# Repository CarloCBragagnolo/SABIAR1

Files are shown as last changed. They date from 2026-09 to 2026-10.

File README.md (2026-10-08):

# SABIAR1



Project files for the Sabiá R1 flight computer

These are the kicad files for the ESP32S3 based flight computer I designed over the summer, Sabiá R1. This is intended as a practise project to improve my skills in programming and pcb design. There are, however, known issues with the design that anyone who uses this design should adress:
first, in the BOM file attached, one of the current limiting/voltage divider resistors in the pyro channels is 7.5 $\ohm$, when it should be 7.5k, causing the led to fail upon arming the pyro channel. Further, the battery voltage measurement circuit was mistakenly connected to a pin with no ADC, so it does not work. Testing is still ongoing so I will keep this page updated.
## DEPENDENCIES
The computer is dependand on the [LIS3MDL](https://github.com/CarloCBragagnolo/lis3mdl) and [LSM6DS3](https://github.com/CarloCBragagnolo/LSM6DS3) libraries, published by myself and available on arduino, as well as the adafruit BMP280 library, also available on arduino. ArduinoEigenDense is also used to handle linear algebra.
## UPDATE 08/10/2026

I have replaced the faulty resistors with the correct valued ones, and this validated the continuity testing, both at the GPIO pin and the LED. Further, the pyros were tested and shown to work, melting through a thin copper wire at 150ms firing time, drawing a estimated 3 amps. No tests have been conducted on a live pyro charge.

Regarding flight software, the attitude kalman filter has been updated to use the magnetometer for up-down facing disambiguation, allowing for accurate logging throughout the flight envelope. Also, the magnetometer can now take both soft and hard iron calibration. The relevant paremeters were calculated using MagMaster. Furthermore, dead-reckoning was added for the y and z axes. This is very much experimental and is not recomended to be used in any flight logic (eg. deploy parachutes early if too far down range).

## TEST FOOTAGE

https://github.com/user-attachments/assets/4542bc1e-f65c-4ce2-99e9-89a8cd237ede

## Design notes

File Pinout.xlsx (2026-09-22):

1 | BUZZER PWM
2 | PYRO 1
3 | PYRO 2
4 | NC
5 | NC
6 | CS BAROMETER
7 | CS MAGNETOMETER
8 | AVAILABLE
9 | AVAILABLE
10 | CS IMU
11 | MOSI
12 | CLK
13 | MISO
14 | NC
15 | NC
16 | NC
17 | LED1
18 | LED3
19 | NC
20 | NC
21 | LED2
22 | NC
23 | NC
24 | NC
25 | NC
26 | NC
27 | NC
28 | NC
29 | NC
30 | NC
31 | NC
32 | NC
33 | NC
34 | NC
35 | NC
36 | PY1 VOLTAGE - dead
37 | PY2 VOLTAGE - dead
38 | BATT CONT.
39 | NC
40 | NC
41 | NC
42 | NC
43 | NC
44 | NC
45 | NC
46 | NC
47 | NC
48 | NC

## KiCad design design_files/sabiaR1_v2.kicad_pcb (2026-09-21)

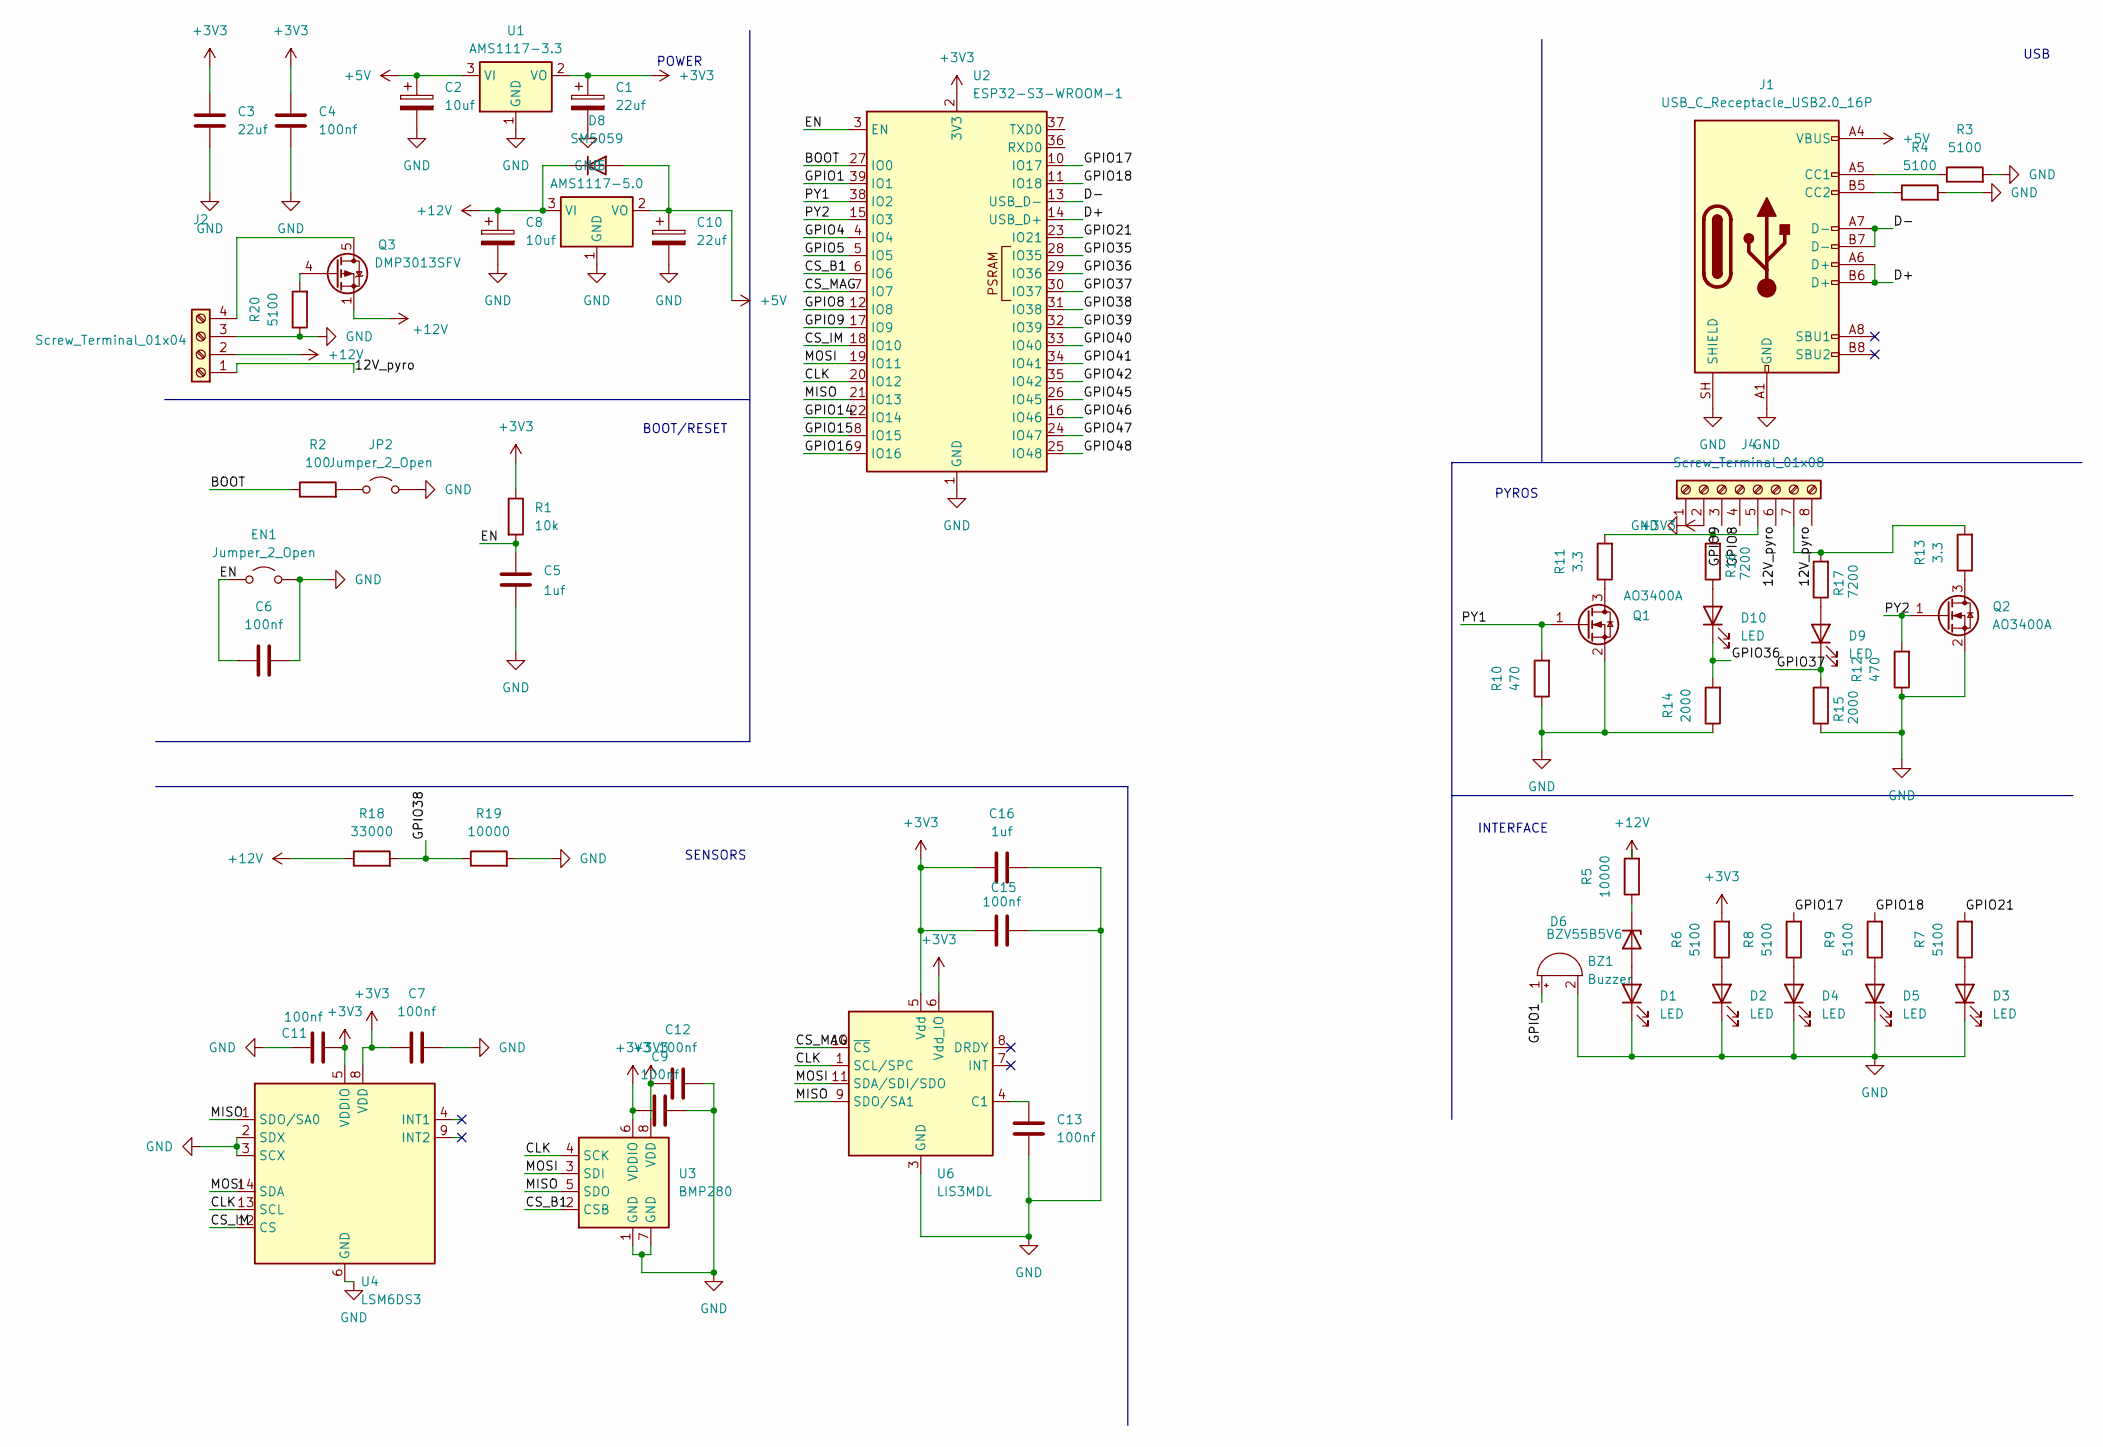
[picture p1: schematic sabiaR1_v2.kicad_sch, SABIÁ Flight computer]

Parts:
BZ1: Buzzer; Buzzer_CUI_CPT-9019S-SMT
C1, C10: 22uf; CP_EIA-3216-18_Kemet-A
C2, C8: 10uf; CP_EIA-3216-12_Kemet-S
C3: 22uf; C_0402_1005Metric
C4, C6, C7, C9, C11, C12, C13, C15: 100nf; C_0402_1005Metric
C5, C16: 1uf; C_0402_1005Metric
D1, D2, D3, D4, D5, D9, D10: LED; LED_0603_1608Metric
D6: BZV55B5V6; D_SOD-923
D8: SM5059; D_SOD-123F
EN1: Jumper_2_Open; SolderJumper-2_P1.3mm_Open_Pad1.0x1.5mm
J1: USB_C_Receptacle_USB2.0_16P; USB_C_Receptacle_GCT_USB4105-xx-A_16P_TopMnt_Horizontal
J2: Screw_Terminal_01x04; TerminalBlock_Phoenix_PT-1,5-4-3.5-H_1x04_P3.50mm_Horizontal
J4: Screw_Terminal_01x08; TerminalBlock_Phoenix_PT-1,5-8-3.5-H_1x08_P3.50mm_Horizontal
JP2: Jumper_2_Open; SolderJumper-2_P1.3mm_Open_Pad1.0x1.5mm
Q1, Q2: AO3400A; SOT-23
Q3: DMP3013SFV; Diodes_PowerDI3333-8
R1: 10k; R_0805_2012Metric
R2: 100; R_0805_2012Metric
R3, R4, R6, R7, R8, R9, R20: 5100; R_0805_2012Metric
R5, R19: 10000; R_0805_2012Metric
R10, R12: 470; R_0805_2012Metric
R11, R13: 3.3; R_2010_5025Metric
R14, R15: 2000; R_0805_2012Metric
R16, R17: 7200; R_0805_2012Metric
R18: 33000; R_0805_2012Metric
U1: AMS1117-3.3; SOT-223-3_TabPin2
U2: ESP32-S3-WROOM-1
U3: BMP280; Bosch_LGA-8_2x2.5mm_P0.65mm_ClockwisePinNumbering
U4: LSM6DS3; LGA-14_3x2.5mm_P0.5mm_LayoutBorder3x4y
U5: AMS1117-5.0; SOT-223-3_TabPin2
U6: LIS3MDL; LGA-12_2x2mm_P0.5mm

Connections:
+3V3: C1.1, C3.1, C4.1, C7.1, C9.2, C11.1, C12.2, C15.2, C16.2, J4.2, R1.1, R6.2, U1.2 (VO), U2.2 (3V3), U3.6 (VDDIO), U3.8 (VDD), U4.5 (VDDIO), U4.8 (VDD), U6.5 (Vdd), U6.6 (Vdd_IO)
+5V: C2.1, C10.1, D8.2 (A), J1.A4 (VBUS), J1.A9 (VBUS), J1.B4 (VBUS), J1.B9 (VBUS), U1.3 (VI), U5.2 (VO)
+12V: C8.1, D8.1 (K), J2.2, Q3.1 (S), Q3.2 (S), Q3.3 (S), R5.2, R18.1, U5.3 (VI)
/12V_pyro: J2.1, J4.6, J4.8
/BOOT: R2.1, U2.27 (IO0)
/CLK: U2.20 (IO12), U3.4 (SCK), U4.13 (SCL), U6.1 (SCL/SPC)
/CS_B1: U2.6 (IO6), U3.2 (CSB)
/CS_IM: U2.18 (IO10), U4.12 (CS)
/CS_MAG: U2.7 (IO7), U6.10 (~CS)
/D+: J1.A6 (D+), J1.B6 (D+), U2.14 (USB_D+)
/D-: J1.A7 (D-), J1.B7 (D-), U2.13 (USB_D-)
/EN: C5.1, C6.1, EN1.1 (A), R1.2, U2.3 (EN)
/GPIO1: BZ1.1 (+), U2.39 (IO1)
/GPIO4: U2.4 (IO4)
/GPIO5: U2.5 (IO5)
/GPIO8: J4.4, U2.12 (IO8)
/GPIO9: J4.3, U2.17 (IO9)
/GPIO14: U2.22 (IO14)
/GPIO15: U2.8 (IO15)
/GPIO16: U2.9 (IO16)
/GPIO17: R8.2, U2.10 (IO17)
/GPIO18: R9.2, U2.11 (IO18)
/GPIO21: R7.2, U2.23 (IO21)
/GPIO35: U2.28 (IO35)
/GPIO36: D10.1 (K), R14.2, U2.29 (IO36)
/GPIO37: D9.1 (K), R15.2, U2.30 (IO37)
/GPIO38: R18.2, R19.1, U2.31 (IO38)
/GPIO39: U2.32 (IO39)
/GPIO40: U2.33 (IO40)
/GPIO41: U2.34 (IO41)
/GPIO42: U2.35 (IO42)
/GPIO45: U2.26 (IO45)
/GPIO46: U2.16 (IO46)
/GPIO47: U2.24 (IO47)
/GPIO48: U2.25 (IO48)
/MISO: U2.21 (IO13), U3.5 (SDO), U4.1 (SDO/SA0), U6.9 (SDO/SA1)
/MOSI: U2.19 (IO11), U3.3 (SDI), U4.14 (SDA), U6.11 (SDA/SDI/SDO)
/PY1: Q1.1 (G), R10.2, U2.38 (IO2)
/PY2: Q2.1 (G), R12.2, U2.15 (IO3)
GND: BZ1.2 (-), C1.2, C2.2, C3.2, C4.2, C5.2, C6.2, C7.2, C8.2, C9.1, C10.2, C11.2, C12.1, C13.2, C15.1, C16.1, D1.1 (K), D2.1 (K), D3.1 (K), D4.1 (K), D5.1 (K), EN1.2 (B), J1.A1 (GND), J1.A12 (GND), J1.B1 (GND), J1.B12 (GND), J1.SH (SHIELD), J2.3, J4.1, JP2.2 (B), Q1.2 (S), Q2.2 (S), R3.2, R4.2, R10.1, R12.1, R14.1, R15.1, R19.2, R20.1, U1.1 (GND), U2.1 (GND), U2.40 (GND), U2.41 (GND), U3.1 (GND), U3.7 (GND), U4.2 (SDX), U4.3 (SCX), U4.6 (GND), U4.7 (GND), U5.1 (GND), U6.2 (GND), U6.3 (GND), U6.12 (GND)
unnamed: D1.2 (A), D6.2 (A)
unnamed: D2.2 (A), R6.1
unnamed: D3.2 (A), R7.1
unnamed: D4.2 (A), R8.1
unnamed: D5.2 (A), R9.1
unnamed: D6.1 (K), R5.1
unnamed: D9.2 (A), R17.1
unnamed: D10.2 (A), R16.1
unnamed: J1.A5 (CC1), R3.1
unnamed: J1.B5 (CC2), R4.1
unnamed: J2.4, Q3.5 (D)
unnamed: J4.5, R11.2, R16.2
unnamed: J4.7, R13.2, R17.2
unnamed: JP2.1 (A), R2.2
unnamed: Q1.3 (D), R11.1
unnamed: Q2.3 (D), R13.1
unnamed: Q3.4 (G), R20.2
unnamed: C13.1, U6.4 (C1)

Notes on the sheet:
SENSORS
PYROS
USB
BOOT/RESET
POWER
INTERFACE

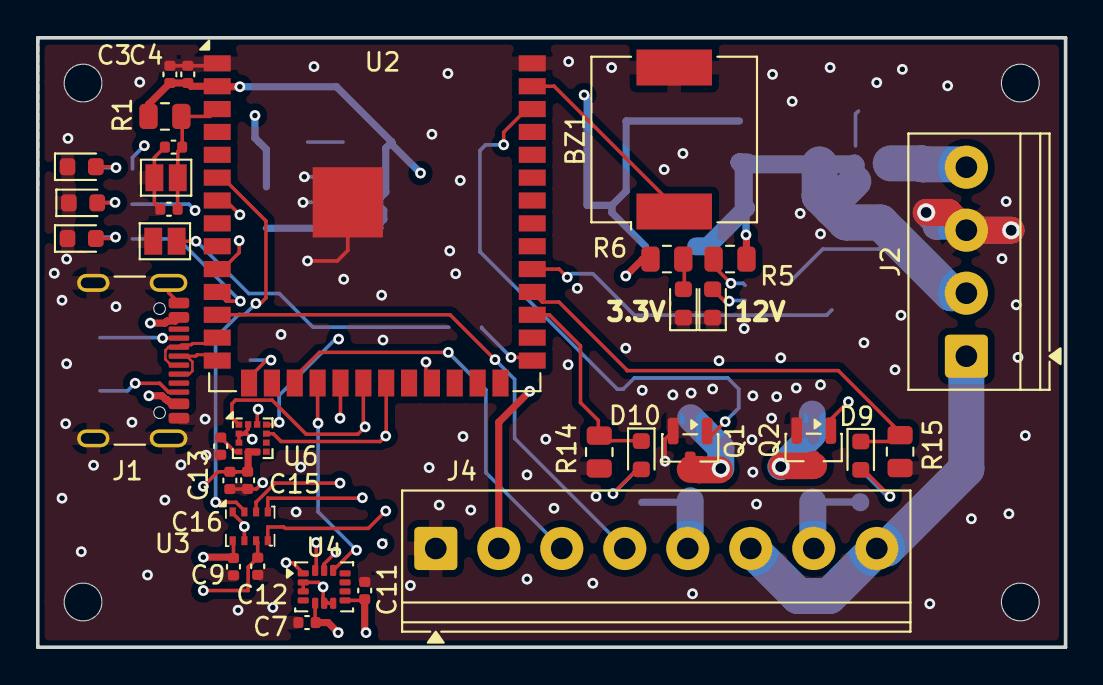
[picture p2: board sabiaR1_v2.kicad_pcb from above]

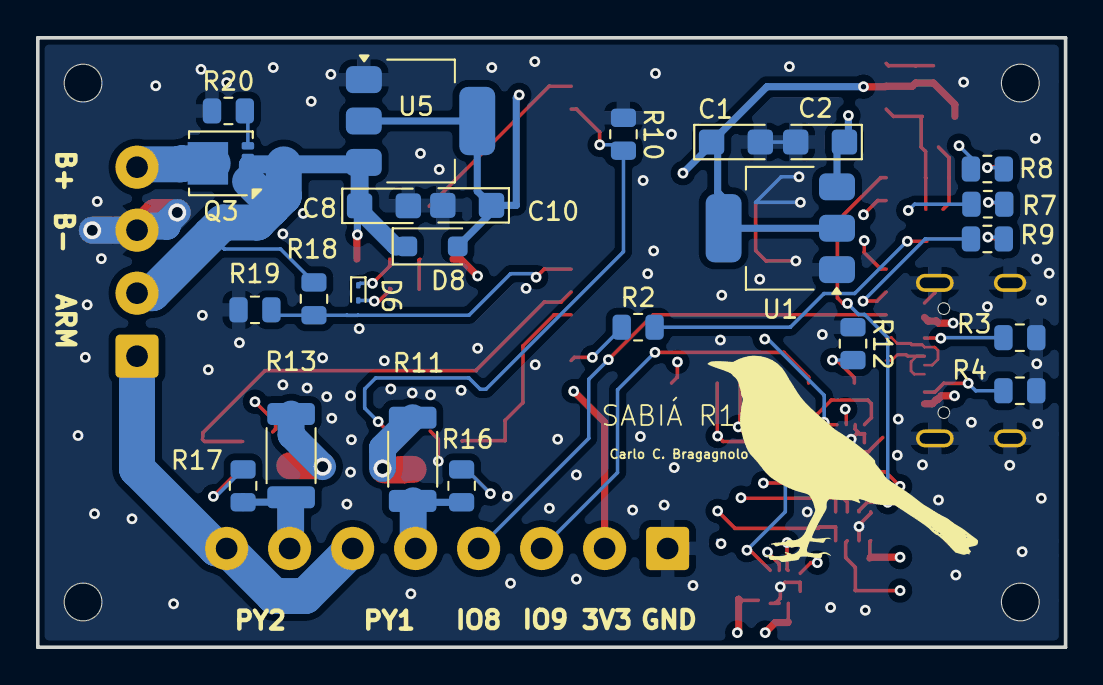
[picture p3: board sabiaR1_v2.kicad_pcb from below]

Board: 4 copper layers, 57.1 x 33.9 mm, 59 parts (24 on the bottom side), 44 nets.

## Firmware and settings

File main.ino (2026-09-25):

#include <rocket.h>
#include <FS.h>
#include <SPIFFS.h>
#include <ArduinoEigenDense.h>

using namespace Eigen;


File file; //internal file

Matrix<double, 3, 3> Soft_iron{
  {1.465, 0.039, 0.05},
  {0.014, 1.531, -0.129},
  {-0.056, 0.07, 1.611}
};
//timekeeping
double t0 = 0;
double t = 0;
double t1;
double deltat = 0;
double t_launch;

//flight logic and file system
String line = "";
int sys_state = 0;
int velocity_counter = 0;
int runs_til_save = 30;
int down_counter =0;

rocket vehicle(1004, 9.815);


void setup() {
  Serial.begin(9600);


  //TEMPORARY, gets magnetometer to shut up
  pinMode(7, OUTPUT);
  digitalWrite(7,HIGH);

  pinMode(17,OUTPUT);
  digitalWrite(17, HIGH);
 

  vehicle.begin();
    
  delay(2000);

  vehicle.calibrate(200);
  
  if (!SPIFFS.begin(true)) {

  Serial.println("Error mounting SPIFFS");
  return;
  }
  delay(1000);
  
  pinMode(21, OUTPUT);
  vehicle.mag_offset(0) = -0.058;
  vehicle.mag_offset(1) = -0.581;
  vehicle.mag_offset(2) = -0.207;
  vehicle.Mag_correction = Soft_iron;
  t = micros(); //need to do this so first loop has valid deltat.
}

void loop() {
  
  while (sys_state < 3){
    deltat = (t - t0)/1000000;
    t0 = micros(); //millis not acc enough
    vehicle.update(deltat);
    Serial.println(String(vehicle.state_vector(0),4) + "," + String(vehicle.state_vector(1),4) + "," + String(vehicle.state_vector(2),4) + ","  + String(vehicle.forwardness, 4) + ", " + String(sqrt(vehicle.state_covariance(0,0))));
    //Serial.println(String(vehicle.barometric_velocity(deltat),4) + "," + String((deltat),6) + "," + String(vehicle.altitude));
    //Serial.println(String(vehicle.euler_attitude(0), 4) + "," + String(vehicle.euler_attitude(1), 4) + "," + String(vehicle.euler_attitude(2), 4) + ","  + String(vehicle.forwardness, 4));
    //Serial.println(String(vehicle.yz_state(0), 4) + "," + String(vehicle.yz_state(1), 4));
    //Serial.println(vehicle.orientation);
    //delay(5);
    

    if (sys_state == 0){ //ground
      if ((vehicle.detect_liftoff() && ((t/1000000) > 5))){
        sys_state += 1;
        t_launch = t;
      }
    }
    if (sys_state == 1){//pre apogee, detect and log data
      t1 = (t-t_launch)/1000000;
      line += String(t1) + "," + String(vehicle.state_vector(0),4) + "," + String(vehicle.state_vector(1),4) + "," + String(vehicle.state_vector(2),4) + ","
      + String(vehicle.altitude,4) + "," + String(vehicle.acc_raw(0),4) + "," +  String(vehicle.forwardness, 4) + "," + String(sys_state) + "\n"; 

      if (runs_til_save ==0){
      runs_til_save = 30;
      //file = SPIFFS.open("/file.txt", FILE_APPEND); //logs data every 30 reads. oppening and closing files takes too long to do it every time (10x sensor rate improvement this way)
      //file.print(line);
      //file.close();
      line = "";
      }

      if(vehicle.detect_apogee()){
        sys_state +=1;
      }
      runs_til_save -=1; 
    }
    if(sys_state == 2){ //waiting for landing
      t1 = (t-t_launch)/1000000;
        line += String(t1) + "," + String(vehicle.state_vector(0),4) + "," + String(vehicle.state_vector(1),4) + "," + String(vehicle.state_vector(2),4) + ","
        + String(vehicle.altitude,4) + "," + String(vehicle.acc_raw(0),4) + "," +  String(vehicle.forwardness, 4) + "," + String(sys_state) + "\n"; 

      if (runs_til_save ==0){
        runs_til_save = 30;
        //file = SPIFFS.open("/file.txt", FILE_APPEND); //logs data every 30 reads. oppening and closing files takes too long to do it every time (10x sensor rate improvement this way)
        //file.print(line);
        //file.close();
        line = "";
      }
      if (sq(vehicle.barometric_velocity(deltat)) < 0.25){
        down_counter +=1;
      }
      else{
        down_counter =0;
      }
      if (down_counter == 1000){
        //sys_state = 3; // landed
        velocity_counter = 0;
        //file = SPIFFS.open("/file.txt", FILE_APPEND); //log last lines of buffered data
        //file.print(line);
        //file.close();
      }
      runs_til_save -=1;
    }
    //Serial.println(String(sys_state) + "," + String(down_counter) + "," + String(vehicle.state_vector(1), 4));
    t = micros();
    }
    
    digitalWrite(21, HIGH);
  }
  

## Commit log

2026-09-22 Add files via upload
    Updated flight software for tilt compensation on the magnetometer.
2026-09-22 Edited software to make hard soft calibration accesible
2026-09-22 Added GPIO reference spreadsheet.
    [Pinout.xlsx]
